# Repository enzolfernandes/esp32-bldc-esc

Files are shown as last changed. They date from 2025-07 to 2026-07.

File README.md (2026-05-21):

# Electronic Speed Controller (ESC) for BLDC Motors

## 📌 Project Overview
This repository contains the full Research and Development (R&D) cycle of a high-performance **Electronic Speed Controller (ESC)** designed for Three-Phase Brushless DC (BLDC) motors. Developed as a Senior Undergraduate Thesis in Electrical Engineering, this project bridges mathematical modeling, power electronics circuit design, and wireless embedded systems architecture.

> ⚠️ **Project Status: Work in Progress (WIP)** > The hardware design, power simulations, and mathematical modeling stages are complete. The project is currently transitioning into the embedded firmware development phase.

---

## 🛠️ Tech Stack & Engineering Tools
* **Hardware & EDA:** Altium Designer, EasyEDA
* **Simulation & Modeling:** LTspice, MATLAB/Simulink
* **Target Architecture (Planned):** C/C++, ESP32 Microcontroller, Bluetooth Core
* **Documentation:** LaTeX

---

## 📁 Repository Structure
```text
├── Docs/               # LaTeX source files for the thesis monograph and academic documentation
├── Hardware/           # Altium Designer schematics, PCB layouts, Gerber files, and BOM
├── Simulation/         # MATLAB/Simulink plant models and LTspice power stage simulations
└── Firmware/           # (Planned) Embedded C++ source code for the ESP32 microcontroller
```
---

## 📈 Engineering Stages & Implementation

### 1. Mathematical Modeling & Plant Simulation (MATLAB/Simulink)
Before physical layout development, the BLDC motor dynamics and switching characteristics were modeled mathematically. 
* **Simulink Models:** Used to evaluate back-EMF behavior, rotor position estimation, and control loop stability.
* **Control Strategy:** Theoretical foundations for vector control and electronic commutation routines were validated to ensure optimal torque and speed efficiency.

### 2. Power Stage & Signal Integrity Simulation (LTspice)
To prevent hardware failures during high-power switching events, critical sections of the circuit were simulated using LTspice.
* Transient analysis of power MOSFET switching characteristics.
* Validation of gate driver circuit performance and bootstrap capacitor sizing.
* Thermal and overcurrent protection threshold evaluation to ensure circuit robustness under power loading.

### 3. Hardware & PCB Design (Altium Designer)
The physical hardware was developed with a focus on power density, thermal dissipation, and signal integrity.
* **Schematic Capture:** Rigorous component specification targeting high efficiency and low noise figures.
* **PCB Layout:** Advanced routing using Altium Designer, featuring optimized power paths to minimize parasitic inductance and separation between high-current power stages and low-voltage digital control signals.
* **Fabrication:** Initial prototyping layouts generated via CNC routing for rapid laboratory bench testing.

---

## 🚀 Development Roadmap (Next Steps)

The next phase focuses on the execution of embedded firmware development and wireless hardware validation:

- [ ] **Firmware Architecture Setup:** Structuring the core C++ application using ESP-IDF/PlatformIO.
- [ ] **Commutation Lobbies:** Implementing hardware interrupts for precise phase switching based on sensor/sensorless feedback.
- [ ] **IoT & Wireless Connectivity:** Developing a **Bluetooth** communication layer for wireless remote control and real-time telemetry monitoring (speed, current, and temperature indexes).
- [ ] **Laboratory Bench Testing:** System debugging using oscilloscopes, logic analyzers, and signal generators to validate torque response and telemetry accuracy under real load conditions.

---

## 📬 Contact & Contributions
If you have questions regarding the hardware architecture, LTspice simulation models, or embedded IoT design, feel free to reach out.

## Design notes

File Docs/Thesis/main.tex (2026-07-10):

%=====================================================
% PREÂMBULO - CONFIGURAÇÕES GERAIS DO DOCUMENTO
%======================================================
\documentclass[12pt, a4paper, openright, oneside, chapter=TITLE, brazilian]{abntex2}

% --- PACOTES DE CODIFICAÇÃO ---
\usepackage[T1]{fontenc}
\usepackage[utf8]{inputenc}
\usepackage{mathptmx}

% --- PACOTES DE LAYOUT E FORMATAÇÃO (ABNT/UNESP) ---
\usepackage[left=3cm, top=3cm, right=2cm, bottom=2cm, headsep=1.5cm]{geometry}
\usepackage{indentfirst} % Indenta o primeiro parágrafo de cada seção
% Usando o comando nativo da classe memoir (base do abntex2) para espaçamento 1,5 [1]
\OnehalfSpacing

% --- HIERARQUIA TIPOGRÁFICA ABNT/UNESP ---
\renewcommand{\ABNTEXchapterfont}{\normalfont\bfseries}
\renewcommand{\ABNTEXchapterfontsize}{\normalsize}
\renewcommand{\ABNTEXsectionfont}{\normalfont\bfseries}
\renewcommand{\ABNTEXsectionfontsize}{\normalsize}
\renewcommand{\ABNTEXsubsectionfont}{\normalfont}
\renewcommand{\ABNTEXsubsectionfontsize}{\normalsize}
\renewcommand{\ABNTEXsubsubsectionfont}{\normalfont\bfseries\itshape}
\renewcommand{\ABNTEXsubsubsectionfontsize}{\normalsize}
\renewcommand{\ABNTEXsubsubsubsectionfont}{\normalfont\itshape}
\renewcommand{\ABNTEXsubsubsubsectionfontsize}{\normalsize}
% --- PACOTES DE BIBLIOGRAFIA (ABNT) ---
\usepackage{csquotes}
% Opções simplificadas para máxima compatibilidade.
\usepackage[backend=biber, style=abnt]{biblatex}
\addbibresource{bibliografia.bib} % Seu arquivo.bib

% --- PACOTES MATEMÁTICOS ---
\usepackage{amsmath}
\usepackage{amssymb}
\usepackage{mathtools}

% --- PACOTES PARA TABELAS E FIGURAS ---
\usepackage{graphicx}
\graphicspath{{../../}{imagens/}}

\usepackage{booktabs}
\usepackage{multirow}
\usepackage{array}
\usepackage[table]{xcolor}
\usepackage{caption}
\usepackage{subcaption}
\usepackage{float}
% --- Configurações automáticas de posicionamento ---
\renewcommand{\topfraction}{0.9}    % Permite que figuras ocupem até 90% do topo da página
\renewcommand{\bottomfraction}{0.8} % Permite que ocupem 80% da base
\renewcommand{\textfraction}{0.05}  % Permite que o texto ocupe apenas 5% da página se necessário
\renewcommand{\floatpagefraction}{0.85} % Só cria uma página só de figuras se elas ocuparem 85% dela
\usepackage[section]{placeins} % Muro invisível automático no final de cada seção
\usepackage{tikz}
\usetikzlibrary{shapes.geometric, arrows.meta, positioning, automata, backgrounds, calc}
\usepackage[american, siunitx]{circuitikz}
\captionsetup{
    format=plain,
    justification=justified,
    singlelinecheck=false,
    font=normalsize,
    labelfont=bf,
    labelsep=period
}
\newcommand{\legendafonte}[1]{{\SingleSpacing\captionsetup{font=footnotesize}\caption*{Fonte: #1}}}

% --- PACOTES ADICIONAIS ---
\usepackage{ragged2e}
\usepackage{soul}

% --- QUEBRA DE LINHA E TIPOGRAFIA ---
\usepackage{microtype}
\usepackage{xurl}
\setlength{\emergencystretch}{3em}
\tolerance=2000
\pretolerance=1000
\makeatletter
\let\breakable@origtexttt\texttt
\DeclareRobustCommand{\breakabletexttt}[1]{%
  \ifmmode
    \breakable@origtexttt{#1}%
  \else
    \begingroup
    \ttfamily
    \let\breakable@us\_
    \def\_{\breakable@us\allowbreak}%
    #1%
    \endgroup
  \fi
}
\let\texttt\breakabletexttt
\newcommand{\code}[1]{{\UrlFont\nolinkurl{#1}}}
\makeatother

% --- CONFIGURAÇÃO DE HIPERLINKS ---
\hypersetup{
    colorlinks=true,
    linkcolor=black,
    citecolor=black,
    urlcolor=black,
    pdftitle={Desenvolvimento e Análise de um Controlador Eletrônico de Velocidade para Motores de Corrente Contínua Sem Escovas},
    pdfauthor={Enzo Luiz Fernandes},
    bookmarksopen=true
}

%=====================================================
% METADADOS DO TRABALHO (PARA CAPA E FOLHA DE ROSTO AUTOMÁTICAS)
%=====================================================

\titulo{Desenvolvimento e Análise de um Controlador Eletrônico de Velocidade para Motores de Corrente Contínua Sem Escovas}
\autor{Enzo Luiz Fernandes}
\instituicao{
  Universidade Estadual Paulista -- UNESP
  \par
  Faculdade de Engenharia -- Câmpus de Ilha Solteira
  \par
  Departamento de Engenharia Elétrica
}
\local{Ilha Solteira}
\data{2026}
\orientador{Prof. Dr. Guilherme de Azevedo e Melo}
\tipotrabalho{Trabalho de Conclusão de Curso}
\preambulo{Trabalho de Conclusão de Curso apresentado à Universidade Estadual Paulista (UNESP), Faculdade de Engenharia, Câmpus de Ilha Solteira, para obtenção do título de Bacharel em Engenharia Elétrica.}

\makeatletter
\renewcommand{\folhaderostocontent}{
  \begin{center}
    {\normalfont\bfseries\imprimirautor}

    \vspace*{\fill}\vspace*{\fill}

    {\normalfont\bfseries\imprimirtitulo}

    \vspace*{\fill}

    \hspace{.45\textwidth}
    \begin{minipage}{.5\textwidth}
      {\SingleSpacing\imprimirpreambulo}
      \par
      \vspace*{1cm}
      Orientador: \imprimirorientador
    \end{minipage}

    \vspace*{\fill}\vspace*{\fill}

    \imprimirlocal
    \par
    \imprimirdata
    \vspace*{1cm}
  \end{center}
}
\makeatother

\begin{document}
\hypersetup{pageanchor=false}

% --- ELEMENTOS PRÉ-TEXTUAIS --
\begin{capa}
    \centering
    {\normalfont\bfseries\MakeUppercase{Universidade Estadual Paulista -- UNESP}\par}
    {Faculdade de Engenharia -- Câmpus de Ilha Solteira\par}
    {Departamento de Engenharia Elétrica\par}
    \vspace*{3cm}
    {\normalfont\bfseries\MakeUppercase{\imprimirautor}}
    \vfill
    \begin{center}
    {\normalfont\bfseries\MakeUppercase{\imprimirtitulo}}
    \end{center}
    \vfill
    {\imprimirlocal}
    \par
    {\imprimirdata}
    \vspace*{1cm}
\end{capa}

\imprimirfolhaderosto*

\begin{fichacatalografica}
    \vspace*{7.2cm}
    {\SingleSpacing\small
    \begin{center}
    \begin{minipage}{0.9\textwidth}
        \fbox{%
        \begin{minipage}{0.95\textwidth}
            \vspace{0.3cm}
            \begin{tabular}{@{}p{1.6cm}p{0.76\textwidth}@{}}
                F363d &
                Fernandes, Enzo Luiz\\
                &
                \hspace*{1.5em}Desenvolvimento e análise de um controlador eletrônico de velocidade para motores de corrente contínua sem escovas / Enzo Luiz Fernandes. -- Ilha Solteira, 2026\\
                &
                \hspace*{1.5em}128 p. : il., tabs., fotos\\[0.8cm]
                &
                \hspace*{1.5em}Trabalho de conclusão de curso (Bacharelado - Engenharia Elétrica) -- Universidade Estadual Paulista (UNESP), Faculdade de Engenharia, Ilha Solteira\\
                &
                \hspace*{1.5em}Orientador: Guilherme de Azevedo e Melo\\[0.8cm]
                &
                \hspace*{1.5em}1. Engenharia elétrica. 2. Motores elétricos. 3. Eletrônica de potência. 4. Sistemas embarcados. 5. Controle automático. I. Título.
            \end{tabular}
            \vspace{0.3cm}
        \end{minipage}}

        \vspace{0.2cm}
        \noindent Sistema de geração automática de fichas catalográficas da Unesp. Dados fornecidos pelo autor(a).
    \end{minipage}
    \end{center}}
\end{fichacatalografica}

% Folha de Aprovação
\begin{folhadeaprovacao} 
\begin{center}
{\normalfont\bfseries\MakeUppercase{\imprimirautor}}
\par\vspace{1cm}
{\normalfont\bfseries\MakeUppercase{\imprimirtitulo}}
\end{center}
\vspace{2cm}
\noindent\imprimirpreambulo
\par
\vspace{1cm}
\noindent Data de aprovação: 6 de julho de 2026.
\par
\vspace{1cm}
\noindent\textbf{BANCA EXAMINADORA}
\par\vspace{\onelineskip}

%Assinaturas 
\assinatura{\imprimirorientador \\ Orientador} 
\assinatura{Dr. Rodrigo Alessandro Nunes de Oliveira \\ Membro da Banca} 
\assinatura{Dr. Pablo Mauricio Portilla Hernandez \\ Membro da Banca} 

\end{folhadeaprovacao}

% RESUMO E ABSTRACT
\begin{resumo}
    Este trabalho apresenta o desenvolvimento e a análise de um protótipo de controlador eletrônico de velocidade (ESC) para motores de corrente contínua sem escovas (BLDC), utilizando o microcontrolador ESP32. A fundamentação teórica aborda a conversão eletromecânica, as constantes $K_T$, $K_V$ e $K_e$, a comutação trapezoidal de seis passos, a modulação por largura de pulso (PWM), a partida \textit{sensorless}, o controle proporcional-integral (PI) e os principais aspectos de eletrônica de potência e software embarcado aplicáveis ao acionamento. A metodologia seguiu uma abordagem de engenharia de sistemas, envolvendo o dimensionamento de uma ponte inversora trifásica, do barramento DC, dos circuitos de acionamento por \textit{gate driver}, das proteções de sobrecorrente e subtensão, do sensoriamento de corrente, da reconstrução de neutro virtual e do condicionamento da força contraeletromotriz para futura detecção de cruzamento por zero (ZCD). Também foram desenvolvidos a PCB protótipo e um \textit{firmware} modular em PlatformIO/FreeRTOS, com camada de abstração de hardware, máquina de estados, comutação seis passos via MCPWM, PWM a $20\,\text{kHz}$, malha de controle a $1\,\text{kHz}$ e interfaces de comando e telemetria. Os resultados incluem validações em LTSpice, análise dos esquemáticos e da PCB, testes estáticos de bancada e avaliação da arquitetura de \textit{firmware}. As simulações confirmaram os caminhos de corrente, o estado de alta impedância da fase não energizada e a necessidade do banco de capacitores do \textit{DC link}. Os ensaios estáticos validaram a manipulação do MCPWM, o tempo morto implementado por \textit{hardware} e as rotinas de proteção. Entretanto, a validação dinâmica integral com motor em rotação foi interrompida após o ensaio a vazio indicar consumo transiente excessivo e disparo da proteção da fonte, compatíveis com falha estrutural no estágio físico de potência. Assim, o objetivo geral foi parcialmente atingido: a base teórica, eletrônica, computacional e de \textit{firmware} foi consolidada e documentada, enquanto a operação completa do ESC permanece dependente de uma nova iteração do \textit{hardware} de potência.
    \par\vspace{\onelineskip}
    \noindent\textbf{Palavras-chave:} Motor BLDC; Controlador Eletrônico de Velocidade; ESP32; Comutação de Seis Passos; Controle Embarcado.
\end{resumo}

\begin{resumo}[Abstract]
\begin{otherlanguage*}{english}
This work presents the development and analysis of an electronic speed controller (ESC) prototype for brushless direct current (BLDC) motors using the ESP32 microcontroller. The theoretical foundation covers electromechanical energy conversion, the $K_T$, $K_V$, and $K_e$ constants, trapezoidal six-step commutation, pulse-width modulation (PWM), sensorless startup, proportional-integral (PI) control, and the main power electronics and embedded software aspects involved in the drive. The methodology followed a systems engineering approach, including the design of a three-phase inverter, the DC bus, gate-driver circuits, overcurrent and undervoltage protections, current sensing, virtual-neutral reconstruction, and back-electromotive-force signal conditioning for future zero-crossing detection (ZCD). A prototype PCB and a modular PlatformIO/FreeRTOS firmware were also developed, with a hardware abstraction layer, finite-state machine, MCPWM-based six-step commutation, $20\,\text{kHz}$ PWM, a $1\,\text{kHz}$ control loop, and command and telemetry interfaces. The results include LTSpice validations, schematic and PCB analysis, static bench tests, and firmware architecture evaluation. The simulations confirmed the current paths, the high-impedance state of the non-energized phase, and the need for the DC-link capacitor bank. The static tests validated MCPWM handling, hardware dead-time insertion, and protection routines. However, full dynamic validation with the motor rotating was interrupted after the no-load test indicated excessive transient current consumption and power-supply protection triggering, consistent with a structural fault in the physical power stage. Therefore, the main objective was partially achieved: the theoretical, electronic, computational, and firmware foundation was consolidated and documented, while complete ESC operation remains dependent on a new iteration of the power hardware.
    \par\vspace{\onelineskip}
    \noindent\textbf{Keywords:} BLDC Motor; Electronic Speed Controller; ESP32; Six-Step Commutation; Embedded Control.
\end{otherlanguage*}
\end{resumo}

% LISTAS E SUMÁRIO

\newpage
\pdfbookmark{\listfigurename}{lof}
\listoffigures*
\cleardoublepage

\pdfbookmark{\listtablename}{lot}
\listoftables*
\cleardoublepage

\begin{siglas}
    \item[ADC] Conversor analógico-digital
    \item[BLDC] Motor de corrente contínua sem escovas
    \item[CAN] \textit{Controller Area Network}
    \item[ESC] Controlador eletrônico de velocidade
    \item[FCEM] Força contraeletromotriz
    \item[FOC] Controle orientado de campo
    \item[FSM] Máquina de estados finitos
    \item[GPIO] Entrada/saída de propósito geral
    \item[HAL] Camada de abstração de hardware
    \item[MCPWM] Módulo de PWM para controle de motores
    \item[OCP] Proteção contra sobrecorrente
    \item[PCB] Placa de circuito impresso
    \item[PI] Proporcional-integral
    \item[PWM] Modulação por largura de pulso
    \item[UVLO] Bloqueio por subtensão
    \item[ZCD] Detecção de cruzamento por zero
\end{siglas}
\cleardoublepage

\begin{simbolos}
    \item[$C_{bus}$] Capacitância total do barramento CC
    \item[$D$] Ciclo de trabalho do sinal PWM
    \item[$f_{sw}$] Frequência de chaveamento
    \item[$I_A$, $I_B$, $I_C$] Correntes das fases A, B e C
    \item[$K_e$] Constante de força contraeletromotriz
    \item[$K_m$] Constante de mérito do motor
    \item[$K_T$] Constante de torque
    \item[$K_V$] Constante de velocidade
    \item[$T_e$] Torque eletromagnético
    \item[$V_{DC}$] Tensão do barramento CC
    \item[$\omega$] Velocidade angular
\end{simbolos}
\cleardoublepage

\pdfbookmark{\contentsname}{toc}
\tableofcontents*
\cleardoublepage

% --- ELEMENTOS TEXTUAIS ---
\hypersetup{pageanchor=true}
\textual

\input{capitulos/2_introducao_teorica.tex}
\input{capitulos/3_metodologia.tex}
\input{capitulos/4_resultados_discussao.tex}
\input{capitulos/5_conclusao.tex}

% --- ELEMENTOS PÓS-TEXTUAIS ---
\postextual
\printbibliography

\end{document}

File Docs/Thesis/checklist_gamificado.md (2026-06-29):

# 💽 GIG: Teste de Bancada ESC (Upload 4.1)

> **Contrato Principal:** Coletar 31 evidências experimentais para o TCC.
> **Drop Point (Pasta de Saída):** `Docs/Thesis/ensaio_bancada/AAAA-MM-DD/` *(Crie no início do dia!)*
>

### 🦾 Loadout do Rigger

- **Atuador Core:** Motor A2212/10T 1400 kV
- **Célula de Força:** Fonte 12 V / limite 3 A
- **Interface de Controle:** PS4 pareado
- **Ghost in the Shell:** Firmware Atual (Build de Teste)
- **Cyberdeck & Ferramentas:** Osciloscópio (1 canal), multímetro, pinça de corrente (opcional), notebook (Wi-Fi `ESC-Dashboard` + serial USB).

---

## 🏙️ NÓ A: Calibração Estática (Setup e Instrumentação)

Motor Desconectado. Configurações iniciais.

### ID 14: Offset INA240

- [x] **Extração Concluída (Com Reserva)**
**Ação:** Boot completo (Wi-Fi AP + PS4). Multímetro DC em OUT de cada INA240 (vs SGND). Serial: `INA240 offset`, logs `[Post-WiFi]` e `[Post-PS4]`. IDLE 30 s com motor desconectado e MCPWM desarmado.
**Extrato (Valores):** $V_{off,A}$ = 1670 mV | $V_{off,B}$ = 1480 mV | $V_{off,C}$ = 1510 mV. `[Post-WiFi]` adc_zero = 1660, bench_corr = +10 | `[Post-PS4]` adc_zero = 1640, bench_corr = +30. IDLE $I_A$: 1ª linha +0,01 A, típico +0,3 a 0,9 A, regime $\pm 0{,}1$ A, pico +1,07 A. $I_B/I_C \lesssim \pm 0{,}5$ A.
**Veredito:** Offset aprovado; zero em IDLE aprovado com reserva (~90% dentro de $\pm 0{,}5$ A em A; picos ~1 A). Deriva pós-RF no GPIO 34 (ver Setup 1a na tese).
**Datashard (Arquivo):** `14_ina240_offset.txt`

### ID 15: Ganho INA240

- [ ] **Pulado — limitação de bancada**
**Ação:** Previsto: validar $G = 20\,\text{V/V}$ na fase B ($I_{inj} \approx 1{,}0\,\text{A}$, $\Delta V_{out} \approx 20\,\text{mV}$, critério $|\varepsilon_G| \lesssim 5\,\%$).
**Veredito:** Cancelado. Sem resistor limitador $\geq 1\,\text{W}$ nem protoboard para injeção segura no shunt B (fonte única; estoque limitado a $1/4\,\text{W}$).
**Substituto:** ID 10 (dashboard $\times$ multímetro); OCP ID 02/18 (opcional).
**Datashard (Arquivo):** `15_ina240_ganho.txt` (registro do cancelamento)

### ID 16: Dead-time

- [ ] **Pendente**
**Ação:** PWM 50%, 20 kHz braço A. Tirar 2 fotos com o mesmo trigger (gate AH e gate AL) ou anotar o configurado.
**Extrato (Valores):** $t_{dead,AH \rightarrow AL}$ = ___ ns | $t_{dead,AL \rightarrow AH}$ = ___ ns
**Datashard (Arquivo):** `16_deadtime_AH.png`, `16_deadtime_AL.png`

### ID 17: $V_{GS}$ Bootstrap

- [ ] **Pendente**
**Ação:** Scope no gate HS e LS (50% duty). Verificar platô ~10–15 V (HS) e ~12 V (LS).
**Extrato (Valores):** $V_{GS,HS}$ = ___ V | $V_{GS,LS}$ = ___ V | Droop? [Sim / Não]
**Datashard (Arquivo):** `17_vgs_HS.png`, `17_vgs_LS.png`

### ID 02: Oscilograma OCP

- [ ] **Pendente**
**Ação:** DAC OCP ativo. Forçar OCP aterrando entrada (−) do LM339. 3 capturas (trigger em OC Trip descida): (1) INA240 ch A, (2) GPIO 26, (3) Gate AH.
**Extrato (Valores):** $t_{resposta} \approx$ ___ ns
**Datashard (Arquivo):** `02_ocp_ina240.png`, `02_ocp_octrip.png`, `02_ocp_gate.png`

### ID 18: Latência OCP

- [ ] **Pendente**
**Ação:** A partir das capturas do ID 02, medir tempos de propagação.
**Extrato (Valores):** $t_{OCP,total}$ = ___ ns | $t_{LM339}$ = ___ ns | $t_{IR2110,SD}$ = ___ ns
**Datashard (Arquivo):** `18_ocp_latencia.txt`

### ID 19: Ripple Vbus (AC)

- [ ] **Pendente**
**Ação:** PWM vazio 20 kHz. Scope no barramento, AC Coupling, 20 mV/div.
**Extrato (Valores):** $V_{pp,ripple}$ = ___ mV
**Datashard (Arquivo):** `19_ripple_vbus.png`

### ID 20: Ripple Teórico e ESR

- [ ] **Pendente**
**Ação:** Calcular ESR baseada no ID 19 e na fórmula $\Delta V_C$.
**Extrato (Valores):** $\Delta V_{C,teo}$ = ___ mV | $ESR_{ef}$ = ___ m$\Omega$
**Datashard (Arquivo):** `20_ripple_esr.txt`

### ID 30: Memória PlatformIO

- [ ] **Pendente**
**Ação:** Rodar `pio run` e copiar o bloco RAM/Flash.
**Extrato (Valores):** `.text` = ___ B | `.rodata` = ___ B | `.data` = ___ B | `.bss` = ___ B | RAM = ___ %
**Datashard (Arquivo):** `30_pio_memory.txt`

### ID 29: Heap Livre (Parte 1 — IDLE)

- [ ] **Pendente**
**Ação:** Ler heap via JSON com motor parado (BT+AP).
**Extrato (Valores):** $H_{livre,IDLE}$ = ___ bytes
**Datashard (Arquivo):** Anotar para salvar junto com a parte 2 em `29_heap.txt`

---

## 🌪️ NÓ B: Rampa + Wi-Fi

Motor conectado. Testes de aceleração e estabilidade.

### ID 21: Corrente de Alinhamento

- [ ] **Pendente**
**Ação:** Pinça DC na Fase A; pressionar R2; ler média durante ALIGN.
**Extrato (Valores):** $I_{align}$ = ___ A | Desvio teórico = ___ %
**Datashard (Arquivo):** `21_i_align.txt`

### ID 01: Partida FSM (Oscilograma)

- [ ] **Pendente**
**Ação:** Pinça na Fase A ou tensão Fase–GND. Gravar 30–60 s com R2. Marcar ALIGN, RUN_OPEN e RUN_SPEED.
**Extrato (Valores):** $t_{rampa,med}$ = ___ s
**Datashard (Arquivo):** `01_partida_faseA_scope.png`, `04_rampa_rpm_im.csv`

### ID 04: Gráfico Rampa RPM + Corrente

- [ ] **Pendente**
**Ação:** Exportar CSV da Dash durante o ensaio anterior (R2 completo).
**Extrato (Valores):** Regiões demarcadas com sucesso.
**Datashard (Arquivo):** `04_rampa_rpm_im.png`

### ID 05: Duração Rampa 5 Hz → 300 Hz

- [ ] **Pendente**
**Ação:** Usar o CSV do ID 04 para subtrair $t_2$ (300 Hz) e $t_1$ (5 Hz).
**Extrato (Valores):** $T_{rampa,med}$ = ___ s | $T_{rampa,teo}$ = ___ s | Desvio = ___ %
**Datashard (Arquivo):** `05_rampa_tempo.txt`

### ID 22: Correntes Trifásicas (Partida)

- [ ] **Pendente**
**Ação:** Extrair dados do CSV. Verificar simetria.
**Extrato (Valores):** ALIGN = ___ ms | $f_{el}$ transição = ___ Hz | Simetria: [Sim / Não]
**Datashard (Arquivo):** `22_partida_correntes.png`

### ID 09: Screenshot Dashboard

- [ ] **Pendente**
**Ação:** Motor RUNNING. Navegador em 192.168.4.1. Print Screen.
**Datashard (Arquivo):** `09_dashboard_screenshot.png`

### ID 10: Validação Corrente Dash vs Multímetro

- [ ] **Pendente**
**Ação:** Multímetro em série. Ler $I_{DC}$ no multímetro, `im` e `rpm`.
**Extrato (1500 RPM):** Multímetro = ___ A | Dash = ___ A | $\varepsilon_I$ = ___ %
**Extrato (2000 RPM):** Multímetro = ___ A | Dash = ___ A | $\varepsilon_I$ = ___ %
**Datashard (Arquivo):** `10_validacao_corrente.txt`

### ID 07: Coerência RPM Dashboard ↔ Serial

- [ ] **Pendente**
**Ação:** Comparar `rpm` no JSON vs UART simultaneamente.
**Extrato (Valores):** $\varepsilon$ (1500 RPM) = ___ % | $\varepsilon$ (2000 RPM) = ___ %
**Datashard (Arquivo):** `07_coerencia_rpm.txt`

### ID 11 & 12: Estabilidade Contínua Wi-Fi

- [ ] **Pendente**
**Ação:** Motor RUNNING $\geq$ 6 min. Exportar CSV da dash. Anotar métricas.
**Extrato (Valores):** $T_{ensaio}$ = ___ min | $N$ amostras = ___ | Quedas HTTP = ___ | Heap/Lat estáveis? [S / N]
**Datashard (Arquivo):** `11_csv_estabilidade.png`, `11_ensaio_estabilidade.csv`, `12_estabilidade_notas.txt`

---

## ⚡ NÓ C: Dinâmica

Testes de resposta, limites e stress mecânico.

### ID 23: Determinismo PWM

- [ ] **Pendente**
**Ação:** Motor em regime. Scope em AH, persistência/histograma $\geq$ 1 min. Apertar botões aleatórios no PS4.
**Extrato (Valores):** $T_{min}$ = ___ $\mu$s | $T_{max}$ = ___ $\mu$s | $\sigma_T$ = ___ ns
**Datashard (Arquivo):** `23_pwm_histograma.png`, `23_pwm_periodo.txt`

### ID 24: Degrau PI Corrente

- [ ] **Pendente**
**Ação:** Modo Corrente (`SPEED_MODE = 0`). R2 degrau rápido sobe/desce. Log serial.
**Extrato (Valores):** $K_p$ = ___ | $K_i$ = ___ | $t_s$ = ___ s | $M_p$ = ___ % | $e_{ss}$ = ___ A
**Datashard (Arquivo):** `24_degrau_corrente.png`, `24_degrau_corrente.csv`

### ID 06: Degrau PI Velocidade

- [ ] **Pendente**
**Ação:** Modo Speed (`SPEED_MODE = 1`). Degrau no R2. Medir tempo de acomodação.
**Extrato (Valores):** $K_p^\omega$ = ___ | $K_i^\omega$ = ___ | $t_s$ = ___ s | $M_p$ = ___ %
**Datashard (Arquivo):** `06_degrau_rpm.png`, `notas_pi.txt`

### ID 25: Frequência Mínima (Malha Aberta)

- [ ] **Pendente**
**Ação:** Reduzir R2 lentamente até vibrar/travar.
**Extrato (Valores):** $f_{el,min}$ = ___ Hz ($\approx$ ___ RPM) | Sintoma: ________________
**Datashard (Arquivo):** `25_fel_min.txt`

### ID 26: Stall Mecânico (Boss Fight!)

- [ ] **Pendente**
**Ação:** $I_{ref} \approx 1{,}5$ A. Travar eixo com segurança. Log serial (duty vai a 95%, FAULT). Dar re-arm.
**Extrato (Valores):** $t_{stall,total}$ = ___ ms | $t_{PI,sat}$ = ___ ms | $t_{det}$ = ___ ms | Re-arm limpo? [S / N]
**Datashard (Arquivo):** `26_stall_evento.png`, `26_stall_evento.csv`

---

## 📡 NÓ D: UVLO, BEMF e Métricas de Software

Ensaios de proteção, sinal e processamento.

### ID 03: UVLO Bateria 4S

- [ ] **Pendente**
**Ação:** Baixar tensão da fonte até dar FAULT. Subir até recuperar (debounce). Log serial `v` e `fault`.
**Extrato (Valores):** $V_{trip}$ = ___ V | $V_{rec}$ = ___ V | $t_{debounce} \approx$ ___ ms
**Datashard (Arquivo):** `03_uvlo_vbus.csv`, `03_uvlo_vbus.png`

### ID 08: BEMF Fase Flutuante

- [ ] **Pendente**
**Ação:** Motor no teto em malha aberta (~300 Hz). Scope 1 ch na 3ª fase vs SGND. Escala 5–20 ms/div.
**Extrato (Valores):** Capturar cruzamento por zero e forma trapezoidal.
**Datashard (Arquivo):** `08_bemf_fase_flutuante.png`

### ID 27: Latência Cenário A

- [ ] **Pendente**
**Ação:** BT + Serial (sem Wi-Fi cliente). Motor RUNNING por 30 s. Log `lat`.
**Extrato (Valores):** $t_{tick,min}$ = ___ $\mu$s | $t_{tick,max}$ = ___ $\mu$s | $\bar{t}_{tick}$ = ___ $\mu$s | $\rho_{CPU}$ = ___ %
**Datashard (Arquivo):** `27_ttick_cenario_A.csv`

### ID 28: Latência Cenário B

- [ ] **Pendente**
**Ação:** BT + Wi-Fi AP + Dashboard polling 1 Hz. Motor RUNNING 30 s. Log `lat` e `lmax`.
**Extrato (Valores):** $t_{tick,min,max,\bar{t}}$ = ___ / ___ / ___ $\mu$s | `lmax` = ___ $\mu$s
**Datashard (Arquivo):** `28_ttick_cenario_B.csv`

### ID 29: Heap Livre (Parte 2 — RUNNING)

- [ ] **Pendente**
**Ação:** Ler heap via JSON com motor rodando e dash atualizando.
**Extrato (Valores):** $H_{livre,RUNNING}$ = ___ bytes | $\Delta H$ = ___ | $\eta_{heap}$ = ___ %
**Datashard (Arquivo):** `29_heap.txt`

### ID 31: Síntese Impacto Wi-Fi

- [ ] **Pendente**
**Ação:** Compilar IDs 12, 27, 28 e 29. Calcular diferença máxima.
**Extrato (Valores):** $\Delta t_{tick,max}$ = ___ $\mu$s | $\bar{t}_{tick,B}$ = ___ $\mu$s | Quedas = ___
**Datashard (Arquivo):** `31_sintese_wifi.txt`

---

## 🏆 NÓ E: Side Quest (Opcional)

### ID 13: Boot Antes/Depois

- [ ] **Pendente**
**Ação:** Medir pico de corrente do firmware antigo vs repouso corrigido *(se tiver o binário antigo)*.
**Extrato (Valores):** $I_{pico,antigo}$ = ___ A ou [N/A]
**Datashard (Arquivo):** `13_boot_corrente.png`

---

💡 **Dica Notion:** Selecione os títulos `## NÓ A` … `## NÓ E` e converta em **Toggle Heading 2** para expandir só a fase ativa durante o ensaio.

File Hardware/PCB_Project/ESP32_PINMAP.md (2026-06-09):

# Mapa de pinos ESP32 ↔ ESC (DevKit V1 / DevKitC v4)

Referência para roteamento em `Control.SchDoc` (símbolo **U3** `DEVKIT_V1_ESP32-WROOM-32`) e PCB.

Fonte firmware: [`Firmware/include/board_config.h`](../../Firmware/include/board_config.h)  
Pinout físico: [`Docs/Thesis/imagens/esp32_devkitC_v4_pinlayout.png`](../../Docs/Thesis/imagens/esp32_devkitC_v4_pinlayout.png)

**Coexistência JTAG + ZCD:** JTAG usa GPIO **12–15** (livres de nets ESC). ZCD usa GPIO **16, 17, 5** (U3 **RX2, TX2, D5**).

> **Nota:** “Pino U3” = designador de pino no símbolo Altium (≠ número GPIO). Ex.: U3 pino **17** = **VP = GPIO36**, não GPIO17.

---

## Tabela mestra U3 ↔ GPIO ↔ função ESC / JTAG

| Pino U3 | Rótulo Altium | GPIO | `#define` / função | Net / destino |
|---|---|---|---|---|
| 30 | VIN | — | Alimentação | `Vcc 2 (+)` |
| 16 | EN | — | Reset | NC (botão EN DevKit) |
| 17 | VP | **36** | `PIN_ADC_IC` | `Isense C Out` → INA240 |
| 18 | VN | **39** | `PIN_ADC_VBAT` | `Vcc Supply Sense` |
| 4 | D2 | 2 | Livre | LED DevKit — **não usar ESC** |
| 5 | D4 | **4** | `PIN_SD_C` | `Shutdown C` → IR2110 SD |
| 8 | D5 | **5** | `PIN_ZCD_C` | `ZCD C` → LM339 BEMF (pull-up 10k) |
| 27 | D12 | **12** | **JTAG MTDI** | Header ESP-Prog — **sem ESC** |
| 28 | D13 | **13** | **JTAG MTCK** | Header ESP-Prog |
| 26 | D14 | **14** | **JTAG TMS** | Header ESP-Prog |
| 3 | D15 | **15** | **JTAG MTDO** | Header ESP-Prog |
| 9 | D18 | **18** | `PIN_PWM_CH` | `CH` → IR2110 |
| 10 | D19 | **19** | `PIN_PWM_CL` | `CL` → IR2110 |
| 11 | D21 | **21** | `PIN_PWM_AH` | `AH` → IR2110 |
| 1 | 3V3 | — | Alimentação | `Vmicro Ref` / 3,3 V |
| 12 | RX0 | 3 | Livre | UART0 programação — **não usar** |
| 13 | TX0 | 1 | Livre | UART0 programação — **não usar** |
| 6 | RX2 | **16** | `PIN_ZCD_A` | `ZCD A` → LM339 BEMF |
| 7 | TX2 | **17** | `PIN_ZCD_B` | `ZCD B` → LM339 BEMF |
| 14 | D22 | **22** | `PIN_PWM_AL` | `AL` → IR2110 |
| 15 | D23 | **23** | `PIN_PWM_BL` | `BL` → IR2110 |
| 23 | D25 | **25** | `PIN_VDAC_REF` | `Vdac Ref` → LM339 OCP (+) DAC1 |
| 24 | D26 | **26** | `PIN_OC_TRIP` | `OC Trip` ← LM339 wired-OR |
| 25 | D27 | **27** | `PIN_PWM_BH` | `BH` → IR2110 |
| 21 | D32 | **32** | `PIN_SD_A` | `Shutdown A` → IR2110 SD |
| 22 | D33 | **33** | `PIN_SD_B` | `Shutdown B` → IR2110 SD |
| 20 | D35 | **35** | `PIN_ADC_IB` | `Isense B Out` → INA240 |
| 19 | D34 | **34** | `PIN_ADC_IA` | `Isense A Out` → INA240 |
| 2, 29 | GND | — | Terra | `SGND` |

### Resumo por categoria

| Categoria | GPIO | Rótulos U3 |
|---|---|---|
| PWM MCPWM | 21, 22, 27, 23, 18, 19 | D21, D22, D27, D23, D18, D19 |
| Shutdown IR2110 | 32, 33, 4 | D32, D33, D4 |
| ADC1 (Wi-Fi OK) | 34, 35, 36, 39 | D34, D35, VP, VN |
| OCP LM339 | 25 (DAC), 26 (in) | D25, D26 |
| ZCD BEMF (reserva) | 16, 17, 5 | RX2, TX2, D5 |
| JTAG / ICE | 12, 13, 14, 15 | D12, D13, D14, D15 |
| Livres | 1, 2, 3 | TX0, D2, RX0 |

---

## Bloco JTAG (ESP-Prog)

| Sinal JTAG | GPIO | Rótulo U3 | Pino U3 |
|---|---|---|---|
| TDI / MTDI | 12 | D12 | 27 |
| TCK / MTCK | 13 | D13 | 28 |
| TMS / MTMS | 14 | D14 | 26 |
| TDO / MTDO | 15 | D15 | 3 |
| GND | — | GND | 2 ou 29 |

Recomendação PCB: header dedicado (ex. 2×5); trilhas curtas; **nenhuma** net ESC nestes pinos.

---

## Bloco ZCD BEMF (LM339)

| Net | GPIO | Rótulo U3 | Pino U3 |
|-----|---|---|---|
| ZCD A | 16 | RX2 | 6 |
| ZCD B | 17 | TX2 | 7 |
| ZCD C | 5 | D5 | 8 |

Regras de hardware:

- Saída LM339 **open-collector** + **pull-up 10 kΩ → 3,3 V** em cada fase.
- **GPIO5 (D5):** pino de strapping (VSPI CS) — pull-up externo obrigatório no comparador.
- Firmware: `BOARD_ENABLE_BEMF_ZCD 0` até hardware soldado; depois `1`.

---

## Não usar

GPIO **6–11** (flash SPI interna do módulo WROOM-32).

---

## Histórico de pinagem ZCD

| Versão | ZCD A/B/C | JTAG 12–15 |
|---|---|---|
| Inicial | 16 / 17 / 5 | Livre |
| Otimizado (intermediário) | 12 / 13 / 15 | Conflito |
| **Atual** | **16 / 17 / 5** | **Livre** |

---

## Ação Altium (`Control.SchDoc`)

1. Rotear **ZCD A/B/C** para **RX2, TX2, D5** (U3 pinos 6, 7, 8) — **não** D12/D13/D15.
2. Deixar **D12–D15** apenas para header **ESP-Prog** (No Connect no resto do ESC).
3. Confirmar demais nets conforme tabela mestra (BL em D23, Shutdown C em D4, etc.).
4. Re-exportar [`Docs/Thesis/imagens/esp32_schematic.png`](../../Docs/Thesis/imagens/esp32_schematic.png).

---

## Validação GPIO (sem overlap)

- **ESC ativo:** 4, 5, 16, 17, 18, 19, 21, 22, 23, 25, 26, 27, 32, 33, 34, 35, 36, 39 (18 pinos)
- **JTAG exclusivo:** 12, 13, 14, 15
- **ZCD** compartilha 16, 17, 5 com ESC reserva — mesmos pinos, nets ZCD quando BEMF existir

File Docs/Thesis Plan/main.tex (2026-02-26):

\documentclass[12pt, a4paper]{article}
\usepackage[style=abnt]{biblatex}
\addbibresource{bibliografia.bib}
\usepackage[utf8]{inputenc} %Pacote para acentuação
\usepackage{csquotes}
\usepackage[portuguese,brazilian]{babel}
\usepackage[lmargin=3cm,tmargin=3cm,rmargin=2cm,bmargin=2cm]{geometry} %Formato que lembra a ABNT
\usepackage[T1]{fontenc} %Ajusta o texto que vem de outras fontes
\usepackage{amsmath,amsthm,amsfonts,amssymb,dsfont,mathtools,blindtext} %pacotes matemáticos
\usepackage{blindtext} %Texto aleatório
\usepackage{graphicx} %imagens
\usepackage{indentfirst}
\usepackage{booktabs, multirow} % for borders and merged ranges
\usepackage{soul}% for underlines
\usepackage[table]{xcolor} % for cell colors
\usepackage{changepage,threeparttable} % for wide tables
\usepackage{caption}
\usepackage{float}
\usepackage{multirow}
\usepackage{colortbl}
\usepackage{hhline}
\usepackage{array}
\usepackage{ragged2e}

\begin{document}

%% Capa
\begin{titlepage}
	\begin{center} %centralizar o texto abaixo
		{\begin{figure}[ht]
				\centering
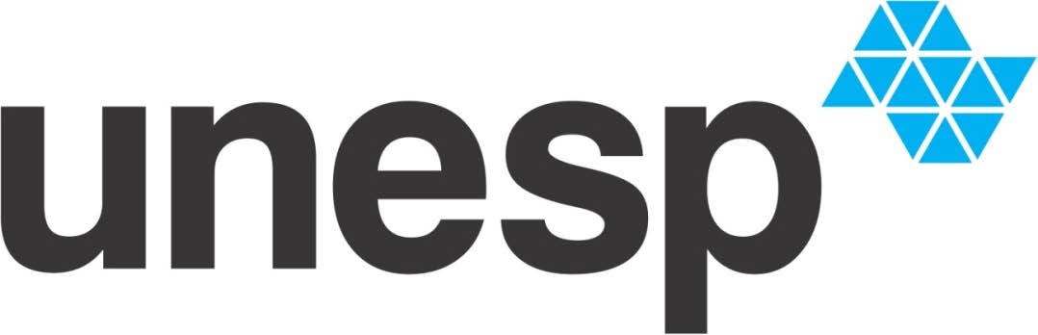
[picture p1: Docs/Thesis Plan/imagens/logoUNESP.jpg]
				
			\end{figure}}
		{\bf \large FEIS – FACULDADE DE ENGENHARIA DE ILHA SOLTEIRA}\\[0.2cm] % o comando \\ "manda" o texto ir para próxima linha
		{\bf \large DEE – DEPARTAMENTO DE ENGENHARIA ELÉTRICA}\\[4cm]

        {\bf \large ENZO LUIZ FERNANDES}\\[4cm]

		{\bf \huge Plano de Trabalho de Graduação}\\[0.2cm] % o comando \bf deixa o texto entre chaves em negrito. O comando \huge deixa o texto enorme

		{\bf \Large Desenvolvimento e Análise de um Controlador Eletrônico de Velocidade para Motores de Corrente Contínua Sem Escovas}\\

	\end{center} %término do comando centralizar

	\vspace*{\fill} % Sempre na parte inferior da página
	\begin{center}
		{\large Ilha Solteira.}\\[0.2cm]

		{\large 2026}

	\end{center}
\end{titlepage}

%% Sumário
\newpage
\tableofcontents
\thispagestyle{empty}
\pagebreak

%-----------------------------------------------
\section{Introdução Teórica}

Os motores BLDC (\textit{Brushless Direct Current Motor}) representam um avanço significativo em relação aos motores CC tradicionais porque eliminam a necessidade de escovas mecânicas para a conversão de energia, resultando em maior rendimento energético, menos desgaste e maior vida útil \cite{hanselman2003brushless}. Esses avanços tecnológicos estão sendo impulsionados pela crescente demanda por sistemas de acionamento mais eficientes, confiáveis e de baixa manutenção em diversas aplicações industriais, comerciais e de consumo. A precisão e controlabilidade dos motores BLDC os tornam ideais para aplicações que exigem alta exatidão de movimento, velocidade e controle de torque, como robótica, automação industrial, veículos elétricos e eletrônicos de consumo.

\subsection{Motores CC Sem Escova}
O princípio de funcionamento dos motores BLDC é baseado em campos magnéticos gerados por ímãs permanentes e enrolamentos de  (Figura \ref{Configuração de um motor DC convencional (A) e motor BLDC (B).}). A comutação da corrente para gerar movimento ocorre eletronicamente, por meio de um controlador dedicado normalmente chamado de ESC (Eletronic Speed Controller), que pode usar ou não sensores durante o processo, eliminando assim a necessidade de escovas mecânicas utilizadas em motores DC tradicionais. Esta abordagem resulta em uma diminuição significativa do desgaste mecânico, aumentando a vida útil do motor e reduzindo a necessidade de manutenção.

\begin{figure}[h]
	\centering
	\caption{Configuração de um motor DC convencional (A) e motor BLDC (B).}
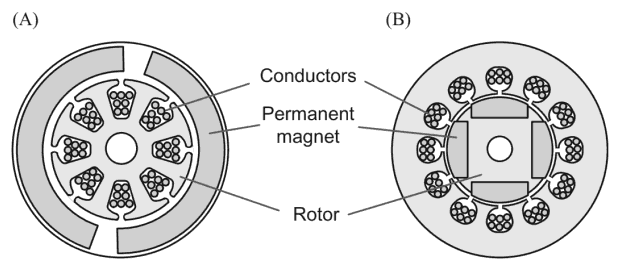
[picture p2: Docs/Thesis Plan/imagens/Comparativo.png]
	
	\caption*{Fonte:\cite{kim2017electric}.}
 \label{Configuração de um motor DC convencional (A) e motor BLDC (B).}
\end{figure}

Os motores BLDC são amplamente utilizados em uma variedade de aplicações, desde eletrônicos de consumo, como ventiladores e ferramentas elétricas, até aplicações industriais e automotivas. Sua capacidade de fornecer um controle preciso de velocidade e posição, juntamente com uma resposta rápida, faz deles a escolha ideal para sistemas que exigem rendimento energético e alta performance.

Apesar das muitas vantagens, os motores BLDC não estão isentos de algumas limitações. A complexidade eletrônica necessária para o controle preciso, o custo inicial potencialmente mais elevado comparado a motores elétricos escovados, a sensibilidade a ambientes de alta temperatura, pois podem gerar a desmagnetização dos imãs permanentes, a exigência de eletrônica de controle especializada, o potencial de ruído eletromagnético (EMI) e a complexidade de manutenção do sistema como um todo são fatores a serem considerados ao escolher essa tecnologia. Cada aplicação específica deve ponderar essas considerações em relação aos benefícios que os BLDC oferecem, como rendimento, durabilidade e controle superior.

\subsubsection{Princípios de Construção}

Motores BLDC são categorizados como síncronos, ou seja, o rotor gira na mesma frequência do campo magnético gerado pelo estator \cite{jahns1984torque}. Também não apresentam o fenômeno de escorregamento que é característico dos motores de indução. Os motores BLDC estão disponíveis em configurações de uma fase, duas fases e três fases, sendo  essa a mais amplamente utilizada, por serem equilibrados em relação a oscilação de torque e custo de construção \cite{hendershot1994design}.

\subsection{Controlador Eletrônico de Velocidade (ESC)}
Os controladores eletrônicos de velocidade, são dispositivos eletrônicos que controlam a velocidade e o torque de motores BLDC. São classificados pela sua corrente e tensão máxima de saída. São constituídos dos seguintes componentes básicos:

\begin{itemize}
\item Circuito de entrada: O circuito de entrada converte a tensão fornecida pela bateria em tensão que pode ser usada pelo circuito de controle utilizando PWM para gerar uma tensão média desejada que será fornecida ao motor. Também pode inverter a sequência de comutação das fases fazendo com que o sentido de rotação também seja invertido.
\item Circuito de controle: O circuito de controle é responsável por calcular a corrente que deve ser fornecida às bobinas do motor. Normalmente se utilizam de sinais com características de PWM como sinal de referência para definir a velocidade e sentido de rotação.
\item Circuito de saída: O circuito de saída fornece a corrente necessária às bobinas do motor.
\end{itemize}

Além desses componentes básicos, os ESCs para motor BLDC pode incluir os seguintes recursos, além dos já discutidos anteriormente:

\begin{itemize}
\item Filtro de ruído: O filtro de ruído é usado para reduzir o ruído elétrico que pode ser gerado pelo motor.
\item Proteção térmica: A proteção térmica é usada para proteger o motor de superaquecimento.
\item Proteção contra sobrecarga: O ESC pode desligar o motor se ele experimentar correntes superiores às nominais que representam riscos de deterioração das bobinas do motor.
\end{itemize}

\subsection{Princípios de Operação}

 O controlador do motor deve fornecer corrente e tensão adequadas às bobinas do estator do motor, a fim de controlar a velocidade e o torque do motor \cite{jahns1996pulsating}. O circuito básico que realiza esse papel é o de uma ponte inversora trifásica, onde o motor BLDC pode estar conectado em Estrela ou Delta. O controle do circuito de disparo dos transistores do inversor deve ser feito de forma que cada fase do estator seja percorrida por uma corrente com a forma de onda senoidal ou trapezoidal, voltadas respectivamente para alto rendimento e baixo custo. As formas de onda de cada uma das fases devem estar defasadas entre si, permitindo que o motor gire de forma contínua.

\subsubsection{Comutação de Seis Passos}

A comutação de seis passos demanda um sincronismo de disparo dos transistores, de modo que sempre dois deles estejam fechados, formando um circuito tal que a cada $60 ^\circ$ elétricos o par de fases percorridas pela corrente se alterne (Figura \ref{Sequência de acionamento para um BLDC trifásico}). Cada transistor permanece em condução durante $120 ^\circ$ elétricos. Vale ressaltar que os eventos de condução e bloqueio, denominados comutações dos transistores, geram variações na corrente e isso é responsável pelas oscilações no torque do motor \cite{kim2017electric}. 

\begin{figure}[p]
	\centering
	\caption{Sequência de acionamento para um BLDC trifásico.}
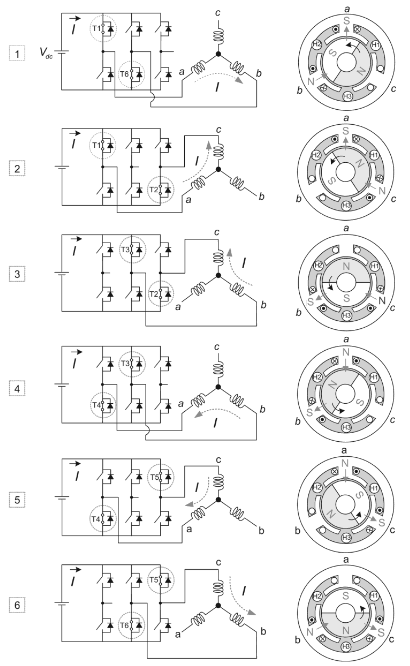
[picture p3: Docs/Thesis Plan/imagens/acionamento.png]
	
	\caption*{Fonte:\cite{kim2017electric}.}
 \label{Sequência de acionamento para um BLDC trifásico}
\end{figure}

Esse é o algoritmo de acionamento dos transistores mais amplamente utilizado para controlar motores BLDC e é também chamada de Controle Trapezoidal. Para se saber quando e quais deles acionar, existem duas opções, saber a posição que o rotor se encontra de forma a acionar o conjunto de transistores seguinte. Para esse tipo de controle se dá o nome de Controle de Malha Fechada. Também é possível acionar os indutores a partir de uma sequência fixa determinada pelo circuito, o que faz com que o rotor comece a girar em algum momento da sequência e siga girando a partir da sequência determinada. Esse tipo de controle é mais simples e de menor custo, porém não tão preciso, recebendo o nome de Controle de Malha Aberta.

 Para a realização do Controle de Malha Fechada é possível usar um sensor de efeito Hall capaz de identificar o campo magnético resultante da interação do campo eletromagnético das bobinas e do campo magnético dos imãs permanentes do rotor, indicando a seção que o campo eletromagnético resultante encontra-se, ou seja, sua posição angular. Partindo dessa referência, se pode saber quais transistores devem ser acionadas para que o rotor continue a girar. A utilização de sensor Hall também propicia a determinação da velocidade angular do motor. Esse método é mais complexo e de maior custo, porém garante uma maior confiabilidade em relação a velocidade.

Quando a aplicação necessita que o motor possua apenas uma velocidade, a fonte de alimentação de tensão fixa é suficiente, mas para casos onde é necessário varia a velocidade do motor precisa-se de uma ponte trifásica com controle PWM, um ESC por exemplo, entretanto essa técnica demanda a utilização de controladores que comparem a velocidade desejada da medida no rotor.

\newpage

\subsubsection{Modulação por Largura de Pulso}

Fontes de tensão fixa, como baterias, são as mais acessíveis do mercado. A partir delas, é possível gerar uma tensão média de alimentação variável utilizando uma técnica conhecida como PWM (Modulação por Largura de Pulso), permitindo o controle de velocidade de um BLDC. Para isso, utiliza-se um circuito simples capaz de transformar a tensão contínua em uma onda quadrada de frequência fixa e amplitude igual à tensão da fonte de alimentação. A própria ponte trifásica pode ajustar a largura dos pulsos, fazendo com que a tensão média entregue à ponte inversora seja proporcional à velocidade desejada (Figura \ref{Modulação por largura de pulso utilizando uma fonte de 100V}).

\begin{figure}[h]
	\centering
	\caption{Modulação por largura de pulso utilizando uma fonte de $100V$.}
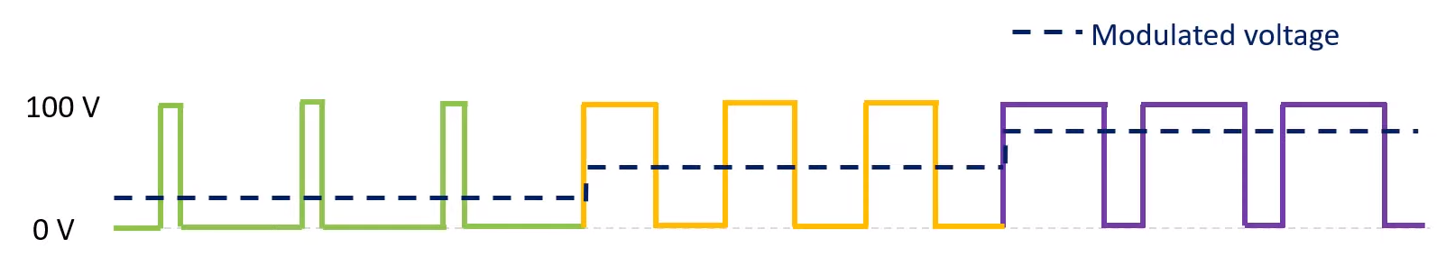
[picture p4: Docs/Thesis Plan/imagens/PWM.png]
	
	\caption*{Fonte:\cite{matlabBLDC}.}
 \label{Modulação por largura de pulso utilizando uma fonte de 100V}
\end{figure}

\subsubsection{Outros Algoritmos de Controle}

Além do Controle Trapezoidal existem outras formas de controle que envolvem algorítimos mais complexos, como o Controle de Torque Vetorial e o Controle de Campo Orientado, ambos em malha fechada.

No controle de torque vetorial, o controlador de motor calcula a corrente que deve ser fornecida às bobinas do estator usando um modelo matemático do motor. O modelo matemático do motor descreve a relação entre a corrente nas bobinas do estator, o campo magnético do rotor e o torque produzido pelo motor. O controlador vetorial de torque do motor calcula o torque desejado e, em seguida, usa o modelo matemático do motor para calcular a corrente necessária para produzir o tal torque. Este controle é um método preciso e flexível que pode ser usado em uma variedade de aplicações. Ele é adequado para aplicações onde a exatidão de velocidade e torque é crítica

No controle de campo orientado, o controlador do motor calcula a corrente que deve ser fornecida às bobinas do estator usando a orientação do campo magnético do rotor. O controlador de motor usa um sensor para medir a orientação do campo magnético do rotor, sendo que o sensor envia um sinal para o controlador, o utiliza sinal para calcular a corrente necessária para manter o campo magnético do rotor na orientação desejada. O controle de campo orientado é um método preciso e eficiente que pode ser usado em aplicações de alta velocidade.

\pagebreak

\subsection{Vantagens e Desvantagens no uso de motores BLDC}
Os motores sem escovas, ou BLDC, apresentam diversas vantagens que contribuem para seu destaque em várias aplicações. O rendimento é uma característica proeminente, uma vez que convertem mais eficientemente a energia elétrica em torque quando comparados aos motores com escovas. Isso implica em uma demanda menor de energia para gerar a mesma quantidade de torque, resultando em um melhor desempenho global. A durabilidade é significativamente aprimorada, visto que a vida útil estendida desses motores está relacionada à ausência das escovas, componentes propensos a desgaste em motores convencionais.

Os motores de indução trifásicos (MIT) são concorrentes diretos dos motores BLDC, sendo que ambos são amplamente utilizados em diversas aplicações, cada uma com suas características distintas e vantagens específicas. Os motores de indução trifásicos são conhecidos pela sua confiabilidade, simplicidade de construção e custo relativamente baixo, quando comparado aos BLDC, utilizando os princípios da indução eletromagnética para gerar o torque e velocidade necessários para a aplicação. Embora tenham menor custo de produção quando comparados com os motores BLDC e podem ser controlados utilizando os mesmos protocolos, os MITs tendem a ter uma densidade de potência e torque menor em comparação com os motores BLDC, principalmente em baixas velocidades, o que pode ser uma consideração importante em aplicações que requerem alta potência em um espaço limitado. No entanto, os MITs apresentam melhor rendimento em operações de baixo torque, o que pode ser relevante em aplicações de mobilidade, como em veículos elétricos.

Os motores BLDC são conhecidos por seu rendimento energético superior, controle preciso de velocidade e torque, além de uma vida útil mais longa devido à ausência de escovas mecânicas \cite{gieras2009permanent}. Embora os BLDCs tenham um custo inicial mais elevado em comparação com os MITs, eles oferecem uma operação mais eficiente, especialmente em condições de carga variável e velocidade ajustável.

Em resumo, os motores sem escovas oferecem um conjunto de vantagens notáveis, incluindo rendimento aprimorado, operação mais silenciosa, maior durabilidade e menor necessidade de manutenção. Contudo, esses benefícios vêm com um custo inicial mais elevado e a exigência de um controlador de velocidade, o que pode tornar sua implementação menos acessível em certos contextos. A escolha entre motores com escovas e sem escovas dependerá das prioridades específicas de uma aplicação, considerando tanto os benefícios quanto as limitações de cada tecnologia.

\pagebreak

\subsection{Aplicações}
Os motores BLDC são amplamente utilizados em diversas aplicações devido às suas características únicas, como elevado rendimento, alta densidade de potência, baixo ruído, baixa manutenção e longa vida útil. Esses motores são preferidos em aplicações que necessitam de controle preciso de torque com oscilações inferiores em comparação com outros motores.

Uma das principais aplicações dos motores BLDC é em veículos elétricos, como carros, motocicletas, bicicletas e \textit{scooters} \cite{chau2007emerging}. Com o aumento da demanda por veículos elétricos, espera-se que os motores com tecnologia derivada do BLDC desempenhem um papel vital na indústria automotiva. Esses motores são usados para acionar o sistema de propulsão do veículo, fornecendo torque e potência para as rodas. Eles são preferidos em veículos elétricos devido à seu alta rendimento, baixo ruído e baixa manutenção. Essas motores são usados em aplicações que exigem alta precisão, controle de velocidade e torque, e baixo ruído.

\section{Objetivos}
Estudar o princípio de funcionamento de um controlador de motores Brushless, tornando possível o projeto e desenvolvimento de um protótipo que possa oferecer uma operação suave e precisa em diferentes cenários de aplicação.

\section{Metodologia}
O desenvolvimento do ESC será realizado em três etapas principais. A primeira conta com uma simulação computacional do sistema para entender a transformação da energia elétrica e a coordenação dos chaveamentos, analisando o controle de rotação e velocidade do motor. Em seguida, na fase de projeto, serão definidos os requisitos mínimos, escolhidos os componentes eletrônicos e desenvolvido o circuito, incluindo controle de tensão, corrente com sinais PWM e proteções. Por último, na prototipagem, o controlador será montado em uma PCB, programado e testado em laboratório para garantir o funcionamento e identificar melhorias.

\subsection{Simulação}
Para o desenvolvimento de um ESC, primeiramente, apresenta-se a simulação do sistema via software, permitindo assim um maior entendimento de cada etapa de transformação da energia elétrica, como a metodologia adotada para coordenação dos chaveamentos, sem as limitações físicas impostas na implementação do circuito real. A simulação gera uma análise teórica funcional sobre o controle de sentido de rotação e velocidade imposta ao motor.

\pagebreak

\subsection{Projeto}
Para a elaboração do projeto físico é necessário o levantamento dos requisitos mínimos que o projeto deve atender, como a categoria de motores que deve atender e sua fonte de alimentação. Em seguida será necessária a seleção dos componentes eletrônicos (drivers, transistores, bateria, entre outros), considerando características como um controlador adequado, tensão de operação, frequência de comutação, corrente máxima suportada e possíveis proteções para o sistema.

O projeto do circuito começa pelo controle de tensão, em seguida será projetado o controle de corrente fornecida às bobinas do motor através de sinais de PWM para controle de velocidade e sentido de rotação, ou seja o drive para motor BLDC e recursos adicionais como proteções térmicas ou de sobrecarga.

\subsection{Prototipagem}
Com o fim do projeto do circuito inicia-se a implementação do controlador em uma placa de circuito impresso (PCB) por meio de um software de design eletrônico. Com a montagem dos componentes na PCB, será necessária a programação do microcontrolador implementado a lógica de chaveamento e outras funções. Também serão realizados teste de funcionamento em laboratório para garantir o funcionamento correto do circuito e levantar possíveis melhorias ou correções. Após as devidas correções serão realizados testes de desempenho afim de verificar se o projeto atende os requisitos estabelecidos de potência e tempo de resposta.

Todas as partes relevantes durante o trabalho de graduação serão documentadas através da redação do relatório acadêmico e apresentação para a defesa do trabalho de graduação.

\section{Cronograma}

O desenvolvimento deste trabalho, está previsto nas seguintes etapas e distribuído de acordo com a Tabela \ref{Cronograma proposto de atividades.}:

\begin{table}[h]
\centering
\caption{Cronograma atualizado de atividades do projeto.}
\label{Cronograma proposto de atividades.}
\resizebox{\linewidth}{!}{%
\begin{tabular}{|c|l|c|c|c|c|c|} 
\cline{3-7}
\multicolumn{1}{c}{} & \multicolumn{1}{c|}{} & \multicolumn{5}{c|}{\textbf{Mês (2026)}} \\ 
\cline{3-7}
\multicolumn{1}{l}{} &  & 02 & 03 & 04 & 05 & 06 \\ 
\hline
\multirow{7}{*}{\textbf{Atividades}} & Simulação do Circuito & {\cellcolor[rgb]{0.753,0.753,0.753}} & {\cellcolor[rgb]{0.753,0.753,0.753}} &  &  &  \\ 
\hhline{|~------|}
 & Projeto da Placa (PCB) e Compras & {\cellcolor[rgb]{0.753,0.753,0.753}} & {\cellcolor[rgb]{0.753,0.753,0.753}} &  &  &  \\ 
\hhline{|~------|}
 & Prototipagem e Soldagem &  & {\cellcolor[rgb]{0.753,0.753,0.753}} & {\cellcolor[rgb]{0.753,0.753,0.753}} &  &  \\ 
\hhline{|~------|}
 & Testes Iniciais (Sinais e PWM) &  &  & {\cellcolor[rgb]{0.753,0.753,0.753}} & {\cellcolor[rgb]{0.753,0.753,0.753}} &  \\ 
\hhline{|~------|}
 & Correções e Ajustes Físicos &  &  &  & {\cellcolor[rgb]{0.753,0.753,0.753}} &  \\ 
\hhline{|~------|}
 & Testes de Carga com o Motor &  &  &  & {\cellcolor[rgb]{0.753,0.753,0.753}} & {\cellcolor[rgb]{0.753,0.753,0.753}} \\ 
\hhline{|~------|}
 & Escrita do Texto e Defesa &  &  &  & {\cellcolor[rgb]{0.753,0.753,0.753}} & {\cellcolor[rgb]{0.753,0.753,0.753}} \\
\hline
\end{tabular}
}
\caption*{Fonte: Produção do próprio autor.}
\end{table}

%% Bibliografia
\newpage
\printbibliography[heading=bibintoc, title={Bibliografia}]
\pagebreak

%% Assinaturas
\newpage
\section*{Assinaturas}
\addcontentsline{toc}{section}{Assinaturas}

\begin{center}

\vspace{2cm}
\begin{tabular}{@{}p{7cm}@{}}
	\hrulefill       \\

	\textbf{Aluno:} \\
	Enzo Luiz Fernandes
\end{tabular}

\vspace{2cm}
\begin{tabular}{@{}p{7cm}@{}}
	\hrulefill                     \\
	\textbf{Professor Orientador:} \\
	Guilherme de Azevedo Melo
\end{tabular}

\end{center}
\pagebreak

%-----------------------------------------------
\end{document}

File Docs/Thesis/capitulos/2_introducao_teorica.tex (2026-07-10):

\chapter{Introdução}

Os motores BLDC (\textit{Brushless Direct Current Motor}) representam um avanço significativo em relação aos motores CC tradicionais porque eliminam a necessidade de escovas mecânicas para a conversão de energia, resultando em maior rendimento energético, menos desgaste e maior vida útil \cite{hanselman2003brushless}. Esses avanços tecnológicos estão sendo impulsionados pela crescente demanda por sistemas de acionamento de maior rendimento, confiáveis e de baixa manutenção em diversas aplicações industriais, comerciais e de consumo. A precisão e controlabilidade dos motores BLDC os tornam ideais para aplicações que exigem alta exatidão de movimento, velocidade e controle de torque, como robótica, automação industrial, veículos elétricos e eletrônicos de consumo.

\input{capitulos/1_objetivos.tex}

\section{Motores CC Sem Escova}
O princípio de funcionamento dos motores BLDC é baseado em campos magnéticos gerados por ímãs permanentes e enrolamentos de  (Figura \ref{fig:motor-dc-bldc-comparativo}). A comutação da corrente para gerar movimento ocorre eletronicamente, por meio de um controlador dedicado normalmente chamado de ESC (Eletronic Speed Controller), que pode usar ou não sensores durante o processo, eliminando assim a necessidade de escovas mecânicas utilizadas em motores DC tradicionais. Esta abordagem resulta em uma diminuição significativa do desgaste mecânico, aumentando a vida útil do motor e reduzindo a necessidade de manutenção. Os motores BLDC são amplamente utilizados em uma variedade de aplicações, desde eletrônicos de consumo, como ventiladores e ferramentas elétricas, até aplicações industriais e automotivas. Sua capacidade de fornecer um controle preciso de velocidade e posição, juntamente com uma resposta rápida, faz deles a escolha ideal para sistemas que exigem rendimento energético e alta performance.

\begin{figure}[H]
	\centering
	\caption{Configuração de um motor DC convencional (A) e motor BLDC (B).}
	
	\legendafonte{\cite{kim2017electric}.}
 \label{fig:motor-dc-bldc-comparativo}
\end{figure}

Apesar das muitas vantagens, eles não estão isentos de algumas limitações. A complexidade eletrônica necessária para o controle preciso, o custo inicial potencialmente mais elevado comparado a motores elétricos escovados, a sensibilidade a ambientes de alta temperatura, pois podem gerar a desmagnetização dos imãs permanentes, a exigência de eletrônica de controle especializada, o potencial de ruído eletromagnético (EMI) e a complexidade de manutenção do sistema como um todo são fatores a serem considerados ao escolher essa tecnologia. Cada aplicação específica deve ponderar essas considerações em relação aos benefícios que os BLDC oferecem, como rendimento, durabilidade e controle superior.

São categorizados como síncronos, ou seja, o rotor gira na mesma frequência do campo magnético gerado pelo estator \cite{jahns1984torque}. Também não apresentam o fenômeno de escorregamento que é característico dos motores de indução. Os motores BLDC estão disponíveis em configurações de uma fase, duas fases e três fases, sendo  essa a mais amplamente utilizada, por serem equilibrados em relação a oscilação de torque e custo de construção \cite{hendershot1994design}.

A nomenclatura "Brushless DC" pode gerar uma interpretação equivocada. Embora alimentado por uma fonte de corrente contínua (DC), o motor BLDC é, em sua essência, um motor síncrono de ímãs permanentes (PMSM) \parencite{maquinasEletricasFitzgerald}. A rotação é induzida por campos magnéticos girantes gerados nos enrolamentos do estator, que são alimentados por formas de onda de corrente alternada (AC) sintetizadas por um controlador eletrônico. Portanto, a designação "DC" refere-se à fonte de alimentação externa, e não ao princípio físico de operação interna, que requer uma lógica de controle sofisticada para operar \parencite{ti2013sensorless}.

Nesse contexto, a performance do sistema é governada por parâmetros intrínsecos que descrevem a física da conversão de energia. Duas das mais importantes dessas constantes são a \textbf{constante de torque ($K_T$)} e a \textbf{constante de velocidade ($K_V$)}. Estes parâmetros são a manifestação matemática dos princípios físicos que regem a interação entre os domínios elétrico e mecânico do motor.

\subsection{Fundamentos Físicos da Conversão Eletromecânica}

A operação de um motor elétrico é governada por dois princípios físicos interligados: a Força de Lorentz, que gera o torque, e a Lei da Indução de Faraday, que gera uma força contraeletromotriz.

\subsubsection{A Força de Lorentz e a Condição de Torque Máximo}

A produção de força mecânica em um motor origina-se na Força de Lorentz. Esta lei descreve a força ($\vec{F}$) sobre um condutor de comprimento vetorial ($\vec{L}$) percorrido por uma corrente ($I$) e imerso em um campo magnético ($\vec{B}$). A relação vetorial é:
\begin{equation}
    \vec{F} = I \cdot (\vec{L} \times \vec{B})
\end{equation}
A magnitude desta força, $F = I \cdot L \cdot B \cdot \sin(\theta)$, onde $\theta$ é o ângulo entre o condutor e o campo magnético, é maximizada quando $\sin(\theta) = 1$, o que ocorre precisamente quando $\theta = 90^{\circ}$. Esta condição de ortogonalidade é o princípio mais elementar para a máxima conversão de energia.

Em um motor rotativo, o objetivo é o torque, que pode ser entendido como a interação entre o campo magnético gerado pelo estator ($\vec{B}_{\text{estator}}$) e o campo gerado pelos ímãs permanentes do rotor ($\vec{B}_{\text{rotor}}$). O torque eletromagnético ($\vec{T}_{em}$) é o produto vetorial desses dois campos \cite{vas1998vector}:
\begin{equation}
    \vec{T}_{em} \propto \vec{B}_{\text{estator}} \times \vec{B}_{\text{rotor}}
\end{equation}
A magnitude do torque é, portanto, diretamente proporcional ao seno do ângulo elétrico ($\theta_e$) entre os dois vetores de campo. O torque máximo é alcançado quando este ângulo é mantido em 90 graus elétricos. Manter esta condição de ortogonalidade de forma contínua é o objetivo central das estratégias de controle de alto desempenho, como o Controle Orientado por Campo (FOC), pois garante não apenas o torque máximo para uma dada corrente, mas também o máximo rendimento na conversão eletromecânica.

\subsubsection{A Lei de Faraday}
Simultaneamente à produção de torque, um motor em rotação atua como um gerador. A Lei da Indução de Faraday afirma que a variação do fluxo magnético através de uma espira de fio induz uma força eletromotriz (FEM). Em um motor, o movimento dos ímãs do rotor em relação aos enrolamentos do estator induz uma tensão conhecida como \textbf{força contraeletromotriz (FCEM)}, ou \textit{back-EMF}.

De acordo com a Lei de Lenz, a polaridade desta tensão induzida ($e_a$) se opõe diretamente à tensão terminal ($V$) aplicada ao motor \parencite{infineon2011bldc}. A magnitude da FCEM é diretamente proporcional à velocidade angular ($\omega$) do motor, estabelecendo a ligação física entre o movimento mecânico (velocidade) e um fenômeno elétrico (tensão induzida).

\subsection{Modelo Matemático do Motor e a Definição das Constantes}

Os princípios de Lorentz e Faraday são sintetizados em um modelo matemático que descreve a dinâmica do motor.

\textbf{Equação Elétrica (Lei de Kirchhoff):}
\begin{equation}
    V = e_a + I_a \cdot R_a + L_a \cdot \frac{dI_a}{dt}
\end{equation}
Onde $V$ é a tensão aplicada, $e_a$ é a FCEM de Armadura, $I_a \cdot R_a$ é a queda de tensão resistiva de Armadura e $L_a \cdot \frac{dI_a}{dt}$ é a queda de tensão indutiva de Armadura \parencite{maquinasEletricasFitzgerald}. Vale ressaltar que Armadura é o termo técnico para o enrolamento em motores elétricos, onde a principal conversão de energia acontece.

\textbf{Equação Mecânica (2ª Lei de Newton para Rotação):}
\begin{equation}
    T_e = T_l + J \cdot \frac{d\omega}{dt} + B \cdot \omega
\end{equation}
Onde $T_e$ é o torque eletromagnético, $T_l$ é o torque de carga, $J \cdot \frac{d\omega}{dt}$ é o torque inercial e $B \cdot \omega$ é o torque de atrito viscoso \parencite{maquinasEletricasFitzgerald}.

Dentro deste modelo, as constantes do motor surgem como os fatores de proporcionalidade que conectam os domínios elétrico e mecânico.

\subsection{\texorpdfstring{A constante de Torque $K_T$}{A constante de Torque KT}}
\label{KT}
A constante de torque ($K_T$) define a capacidade de um motor de converter corrente elétrica em torque mecânico. É formalmente definida como a relação linear:
\begin{equation}
    T_e = K_T \cdot I_a
\end{equation}
O valor de $K_T$ não é arbitrário, mas determinado pelas características construtivas do motor \parencite{hendershot1994design}:
\begin{itemize}
    \item \textbf{Força do Campo Magnético ($B$):} Ímãs mais fortes (ex: Neodímio) resultam em um $K_T$ maior.
    \item \textbf{Configuração do Enrolamento:} É diretamente proporcional ao número de espiras ($N$) nos enrolamentos.
    \item \textbf{Geometria do Motor:} Dimensões como o comprimento e o raio do estator influenciam diretamente seu valor.
\end{itemize}
Para um dado torque de carga, um motor com $K_T$ maior demandará uma corrente menor, resultando em menores perdas por efeito Joule ($P = I^2 \cdot R$) e, portanto, maior rendimento.

\subsection{\texorpdfstring{As constantes de Velocidade $K_V$}{As constantes de Velocidade KV}}
\label{KV}

De forma análoga, a relação entre a FCEM e a velocidade é quantificada por constantes.
\begin{itemize}
    \item \textbf{Constante de FCEM ($K_e$):} É a constante física que relaciona a FCEM gerada ($e_a$) com a velocidade angular do motor ($\omega$):
    \begin{equation}
        e_a = K_e \cdot \omega
    \end{equation}
    Assim como $K_T$, $K_e$ (também denotado como $k_b$) depende do projeto físico do motor \parencite{zoltan2012understanding}.

    \item \textbf{Constante de Velocidade ($K_V$):} Muito mais comum em folhas de dados comerciais, $K_V$ é definida como a relação entre a velocidade do motor sem carga e a tensão aplicada, geralmente em unidades de \textbf{RPM/V}. A relação entre $K_V$ e $K_e$ é de simples inversão \parencite{infineon2011bldc}:
    \begin{equation}
        K_V = \frac{1}{K_e}
    \end{equation}
    A FCEM é o mecanismo que limita a velocidade máxima do motor. O motor acelera até que a FCEM ($e_a = K_e \cdot \omega$) se aproxime da tensão de alimentação ($V$), ponto no qual a corrente resultante é apenas suficiente para vencer o atrito.
\end{itemize}

\subsection{\texorpdfstring{A Equivalência entre $K_T$ e $K_e$}{A Equivalência entre KT e Ke}}

Um dos resultados mais notáveis na teoria de motores é a equivalência numérica entre $K_T$ e $K_e$ quando ambas são expressas em unidades do Sistema Internacional (SI): \textbf{Nm/A} para $K_T$ e \textbf{V·s/rad} para $K_e$.
\begin{equation}
    K_T \text{ [Nm/A]} = K_e \text{ [V·s/rad]}
\end{equation}
Esta equivalência não é uma coincidência, mas uma consequência da \textbf{lei da conservação de energia}.

\textbf{Demonstração por Balanço de Potência:}
\begin{enumerate}
    \item A potência elétrica convertida em potência mecânica ($P_{\text{conv}}$) é a parte da potência de entrada que não é perdida como calor nos enrolamentos.

    \item A potência elétrica fornecida à armadura é
    \begin{equation}
        P_{\text{in}} = V \cdot I_a
    \end{equation}
    Substituindo a equação elétrica $V = e_a + I_a R_a$:
    \begin{equation}
        P_{\text{in}} = (e_a + I_a R_a) I_a = e_a I_a + I_a^2 R_a
    \end{equation}
    A parcela $I_a^2 R_a$ corresponde às perdas Joule nos enrolamentos; descontando-as, a potência eletromecanicamente convertida é
    \begin{equation}
        P_{\text{conv}} = e_a I_a
    \end{equation}

    \item A potência mecânica de saída ($P_{\text{mec}}$) é o produto do torque eletromagnético e da velocidade angular:
    \begin{equation}
        P_{\text{mec}} = T_e \cdot \omega
    \end{equation}

    \item Pela conservação de energia, a potência convertida iguala-se à potência mecânica de saída:
    \begin{equation}
        P_{\text{conv}} = P_{\text{mec}}
    \end{equation}

    \item Combinando os itens anteriores, $P_{\text{conv}} = P_{\text{mec}}$ implica
    \begin{equation}
        e_a I_a = T_e \omega
    \end{equation}
    Substituindo as definições $e_a = K_e \omega$ e $T_e = K_T I_a$:
    \begin{equation}
        (K_e \omega) I_a = (K_T I_a) \omega
    \end{equation}

    \item Para qualquer condição de operação não nula, podemos cancelar $\omega$ e $I_a$ de ambos os lados, provando que:
    \begin{equation}
        K_e = K_T
    \end{equation}
\end{enumerate}
Esta prova revela que o mesmo mecanismo de acoplamento eletromagnético que produz torque a partir da corrente (princípio motor, $K_T$) é o que gera tensão a partir do movimento (princípio gerador, $K_e$). Eles são duas manifestações do mesmo fenômeno físico \parencite{zoltan2012understanding, garcia1997modelagem}.

\subsection{Conversão de Unidades}

A elegância teórica é frequentemente obscurecida pelo uso de unidades inconsistentes na prática. A habilidade de converter valores de folhas de dados para o padrão SI é indispensável. A relação prática mais importante é entre $K_T$ e $K_V$:
\begin{equation}
    K_T \text{ [N·m/A]} = \frac{60 \cdot K_V \text{ [RPM/V]}}{2\pi}
\end{equation}
Esta fórmula é derivada diretamente da equivalência $K_T = K_e = 1/K_V$ após a conversão da velocidade para rad/s \parencite{infineon2011bldc}. A tabela abaixo resume as conversões chave.

\begin{table}[H]
\centering
\caption{Unidades de Constantes de Motor e Fatores de Conversão para o SI}
\label{tab:unidades}

\resizebox{\textwidth}{!}{%
\begin{tabular}{llll}
\toprule
\textbf{Parâmetro} & \textbf{Unidade SI} & \textbf{Unidades Comuns Não-SI} & \textbf{Fórmula de Conversão para SI} \\
\midrule
\textbf{Constante de Torque ($K_T$)} & N·m/A & oz-in/A & 1 oz-in/A = 0.00706155 N·m/A \\
 & & mN·m/A & 1 mN·m/A = 0.001 N·m/A \\
\addlinespace
\textbf{Constante de FCEM ($K_e$)} & V·s/rad & V/krpm & 1 V/krpm = 0.009549 V·s/rad \\
\addlinespace
\textbf{Constante de Velocidade ($K_V$)} & rad/(V·s) & RPM/V & 1 RPM/V = 0.10472 rad/(V·s) \\
\bottomrule
\end{tabular}%
}
\legendafonte{Elaborado pelo autor (2026).}
\end{table}

\subsection{\texorpdfstring{A Constante do Motor ($K_m$) como Figura de Mérito}{A Constante do Motor (Km) como Figura de Mérito}}

Uma constante mais fundamental para avaliar a qualidade do projeto de um motor é a \textbf{constante do motor ($K_m$)}:
\begin{equation}
    K_m = \frac{K_T}{\sqrt{R_a}}
\end{equation}
Sua unidade no SI é \textbf{N·m/$\sqrt{\text{W}}$}. $K_m$ representa a capacidade do motor de produzir torque por watt de potência dissipada como calor. Um $K_m$ mais alto indica um motor com maior rendimento na conversão de energia. Notavelmente, $K_m$ é invariante a alterações no enrolamento para um mesmo tamanho de carcaça, tornando-se uma excelente figura de mérito para comparar a qualidade de diferentes projetos de motores \parencite{infineon2011bldc}.

\subsection{Influência da Temperatura}

Embora chamadas de "constantes", $K_T$ e $K_e$ são afetadas pela temperatura. O aquecimento do motor causa uma redução na força magnética dos ímãs permanentes. Como ambas as constantes são diretamente proporcionais à densidade de fluxo magnético, um motor operando em alta temperatura produzirá menos torque para a mesma corrente (menor $K_T$) e precisará girar mais rápido para gerar a mesma FCEM (menor $K_e$, consequentemente um $K_V$ ligeiramente maior), resultando em uma performance geral degradada.

\section{Controlador Eletrônico de Velocidade (ESC)} 
 Os controladores eletrônicos de velocidade, são dispositivos eletrônicos que controlam a velocidade e o torque de motores BLDC. São classificados pela sua corrente e tensão máxima de saída. São constituídos dos seguintes componentes básicos: 

 \begin{itemize} 
 \item Circuito de entrada: O circuito de entrada converte a tensão fornecida pela bateria em tensão que pode ser usada pelo circuito de controle utilizando PWM para gerar uma tensão média desejada que será fornecida ao motor. Também pode inverter a sequência de comutação das fases fazendo com que o sentido de rotação também seja invertido. 
 \item Circuito de controle: O circuito de controle é responsável por calcular a corrente que deve ser fornecida às bobinas do motor. Normalmente se utilizam de sinais com características de PWM como sinal de referência para definir a velocidade e sentido de rotação. 
 \item Circuito de saída: O circuito de saída fornece a corrente necessária às bobinas do motor. 
 \end{itemize} 

 Além desses componentes básicos, os ESCs para motor BLDC pode incluir os seguintes recursos, além dos já discutidos anteriormente: 

 \begin{itemize} 
 \item Filtro de ruído: O filtro de ruído é usado para reduzir o ruído elétrico que pode ser gerado pelo motor. 
 \item Proteção térmica: A proteção térmica é usada para proteger o motor de superaquecimento. 
 \item Proteção contra sobrecarga: O ESC pode desligar o motor se ele experimentar correntes superiores às nominais que representam riscos de deterioração das bobinas do motor. 
 \end{itemize} 

  As equações lineares de um motor DC só são diretamente aplicáveis a um motor BLDC devido à ação sofisticada do seu \textbf{Controlador Eletrônico de Velocidade (ESC)}. O ESC realiza a comutação eletrônica, energizando sequencialmente os enrolamentos do estator para criar um campo magnético giratório. Isso força a complexa máquina AC a se comportar como o motor DC idealizado, tornando as constantes $K_T$ e $K_e$ ferramentas de análise e projeto perfeitamente válidas \parencite{hendershot1994design}.

 \subsection{\texorpdfstring{Consequências Práticas da Seleção de $K_V$}{Consequências Práticas da Seleção de KV}} 

 A seleção de $K_V$ é uma decisão de projeto crítica que estabelece um compromisso fundamental: 
 \begin{itemize} 
 \item \textbf{Motores de Alto $K_V$:} Possuem menos espiras de fio mais grosso. Resultam em baixo $K_T$, baixa resistência e baixa indutância. Para produzir torque, exigem alta corrente, mas atingem altas velocidades. Ideais para aplicações de alta velocidade e baixo torque, como drones de corrida e fusos de usinagem \parencite{tmotor2019kv}. 
 \item \textbf{Motores de Baixo $K_V$:} Possuem mais espiras de fio mais fino. Resultam em alto $K_T$, alta resistência e alta indutância. Geram alto torque com baixas correntes, apresentando maior rendimento para essa finalidade, mas com menor velocidade máxima. Ideais para aplicações de acionamento direto e alto torque, como drones de carga, guinchos e atuadores robóticos \parencite{byod2018kv}. 
 \end{itemize} 

 \subsection{Princípios de Operação} 

 O controlador eletrônico tem a função de fornecer tensão e corrente adequadas às bobinas do estator, visando o controle preciso da velocidade e do torque da máquina \cite{jahns1996pulsating}. A topologia fundamental para esta finalidade é a ponte inversora trifásica, à qual o motor BLDC pode ser acoplado em configuração estrela ou triângulo. O chaveamento dos transistores do inversor deve ser orquestrado de forma que cada fase seja percorrida por uma corrente com forma de onda senoidal ou trapezoidal. A excitação senoidal é voltada para um acionamento de alto desempenho e suavidade, enquanto a trapezoidal destaca-se pela simplicidade de controle e baixo custo de implementação. Para garantir a geração de um campo magnético girante e a rotação contínua do rotor, as formas de onda das três fases devem ser defasadas em 120 graus elétricos entre si.

 \subsubsection{Comutação de Seis Passos} 

 A comutação de seis passos demanda um sincronismo de disparo dos transistores de modo que, no modelo ideal, sempre dois deles estejam fechados: um transistor do lado superior (\textit{high-side}) conectado ao barramento positivo e um transistor do lado inferior (\textit{low-side}) conectado ao barramento negativo. Assim, em cada setor de $60^\circ$ elétricos, duas fases são energizadas e a terceira permanece eletricamente aberta para que sua FCEM possa ser observada (Figura \ref{fig:sequencia-acionamento-bldc}). Cada transistor permanece em condução durante $120^\circ$ elétricos.

 A denominação ``seis passos'', entretanto, descreve apenas os seis estados estacionários comandados pelo controlador ao longo de um ciclo elétrico. Do ponto de vista físico da corrente, cada passagem entre dois setores contém também um intervalo transitório de comutação. Portanto, uma descrição mais completa pode ser entendida como doze subintervalos por ciclo elétrico: seis intervalos de condução principal, nos quais a corrente percorre duas fases, e seis intervalos de transferência, nos quais a corrente da fase que está sendo desligada ainda precisa encontrar um caminho de circulação.

 Esse comportamento ocorre porque os enrolamentos do estator são indutivos. A corrente de um elemento indutivo não pode variar instantaneamente, logo, quando um MOSFET é bloqueado, a corrente que circulava naquela fase não desaparece. Ela força a tensão do terminal da fase a se deslocar até polarizar diretamente o diodo de corpo de algum MOSFET. A corrente que estava circulando pela fase de saída continua fluindo pelo enrolamento da fase de saída e é desviada para um caminho de roda livre formado pelos diodos intrínsecos dos MOSFETs, até que sua energia magnética seja transferida para a outra fase.

 Considere, por exemplo, a transição do setor $A^+B^-$ para o setor $A^+C^-$. Antes da comutação, a corrente principal percorre o caminho $+V_{DC} \rightarrow H_A \rightarrow A \rightarrow B \rightarrow L_B \rightarrow -V_{DC}$, onde $H_A$ representa o transistor superior da fase A e $L_B$ o transistor inferior da fase B. Quando $L_B$ é desligado, a corrente que saía pela fase B continua no mesmo sentido por causa da energia armazenada no indutor. Como o caminho pelo transistor inferior foi aberto, o terminal B é elevado até conduzir pelo diodo de corpo do transistor superior da mesma fase ($H_B$), fechando uma malha de recirculação. Ao mesmo tempo, $L_C$ começa a conduzir e a corrente cresce na nova fase de retorno C. Durante esse intervalo, a corrente se divide entre uma malha antiga em decaimento, associada à fase B, e uma malha nova em crescimento, associada à fase C.

O caso complementar ocorre quando a fase que está saindo é conectada ao terminal positivo do barramento CC. Em uma transição como $A^+C^-$ para $B^+C^-$, o transistor superior de A é bloqueado e a corrente da fase A, que ainda tende a entrar no enrolamento, força o terminal A a conduzir pelo diodo de corpo do transistor inferior de A ($L_A$). Assim, quando um transistor superior é bloqueado, o caminho complementar é formado pelo diodo em antiparalelo do transistor inferior da mesma fase e quando um transistor inferior é bloqueado, o caminho complementar é formado pelo diodo em antiparalelo do transistor superior da mesma fase. A Tabela \ref{tab:subintervalos_comutacao_6step} resume essa sequência para uma rotação elétrica completa.

\begin{table}[H]
\centering
\caption{Estados principais e intervalos transitórios na comutação trapezoidal}
\label{tab:subintervalos_comutacao_6step}
\small
\begin{tabular}{@{}p{1.5cm}p{2.2cm}p{4.3cm}p{5.1cm}@{}}
\toprule
Setor & Estado principal & Caminho principal da corrente & Intervalo de transferência para o próximo setor \\
\midrule
1 & $A^+B^-$ & $+V_{DC} \rightarrow H_A \rightarrow A \rightarrow B \rightarrow L_B \rightarrow -V_{DC}$ & $B$ deixa de ser a fase de retorno; sua corrente decai pelo diodo de $H_B$, enquanto $C$ passa a conduzir por $L_C$. \\
2 & $A^+C^-$ & $+V_{DC} \rightarrow H_A \rightarrow A \rightarrow C \rightarrow L_C \rightarrow -V_{DC}$ & $A$ deixa de ser a fase de alimentação; sua corrente decai pelo diodo de $L_A$, enquanto $B$ passa a conduzir por $H_B$. \\
3 & $B^+C^-$ & $+V_{DC} \rightarrow H_B \rightarrow B \rightarrow C \rightarrow L_C \rightarrow -V_{DC}$ & $C$ deixa de ser a fase de retorno; sua corrente decai pelo diodo de $H_C$, enquanto $A$ passa a conduzir por $L_A$. \\
4 & $B^+A^-$ & $+V_{DC} \rightarrow H_B \rightarrow B \rightarrow A \rightarrow L_A \rightarrow -V_{DC}$ & $B$ deixa de ser a fase de alimentação; sua corrente decai pelo diodo de $L_B$, enquanto $C$ passa a conduzir por $H_C$. \\
5 & $C^+A^-$ & $+V_{DC} \rightarrow H_C \rightarrow C \rightarrow A \rightarrow L_A \rightarrow -V_{DC}$ & $A$ deixa de ser a fase de retorno; sua corrente decai pelo diodo de $H_A$, enquanto $B$ passa a conduzir por $L_B$. \\
6 & $C^+B^-$ & $+V_{DC} \rightarrow H_C \rightarrow C \rightarrow B \rightarrow L_B \rightarrow -V_{DC}$ & $C$ deixa de ser a fase de alimentação; sua corrente decai pelo diodo de $L_C$, enquanto $A$ passa a conduzir por $H_A$. \\
\bottomrule
\end{tabular}
\end{table}

 Dessa forma, o controle é comandado em seis setores, mas a corrente percorre doze situações relevantes: seis caminhos principais de produção de torque e seis caminhos transitórios de roda livre ou regeneração parcial. Durante essas transições, nenhuma fase é instantaneamente desligada em termos eletromagnéticos; a fase de saída permanece conduzindo por diodo por uma fração do período, enquanto a fase de entrada ainda está estabelecendo corrente. A consequente distorção transitória das tensões de fase e a assimetria entre a corrente que decai e a corrente que cresce são as principais causas das oscilações no torque do motor (\textit{torque ripple}) características deste método \cite{kim2017electric, jahns1996pulsating}.
 
 Esse algoritmo de acionamento dos transistores, também chamado de Controle Trapezoidal, é a base para o funcionamento do motor BLDC. Embora seja possível operá-lo em malha aberta (sequência fixa), esta abordagem apresenta baixo rendimento e é propensa à perda de sincronismo sob variações de carga. Portanto, neste trabalho, projeta-se e implementa-se a infraestrutura de \textit{hardware} e \textit{firmware} para um \textbf{ESC trapezoidal \textit{sensorless}}, incluindo os circuitos de reconstrução de neutro virtual, filtragem RC e comparadores LM339 destinados à detecção de cruzamento por zero (ZCD) da FCEM. 
 
 \begin{figure}[H]
    \centering
    \caption{Sequência de acionamento para um BLDC trifásico.}
    
    \legendafonte{\cite{kim2017electric}.}
    \label{fig:sequencia-acionamento-bldc}
\end{figure}

 Nesta etapa de validação, a comutação opera em \textbf{malha aberta} (alinhamento e rampa forçada); a \textbf{transição para comutação em malha fechada orientada por ZCD} permanece como passo subsequente, após a confirmação da sequência 6-step e do condicionamento do sinal, conforme detalhado no Capítulo 4.

 Quando a aplicação necessita que o motor possua apenas uma velocidade, a fonte de alimentação de tensão fixa é suficiente. Para casos onde é necessário variar a velocidade do motor, a técnica de Modulação por Largura de Pulso (PWM) é normalmente empregada. Um ESC, por exemplo, utiliza PWM para ajustar a tensão média aplicada ao motor, controlando assim sua velocidade. Essa técnica, no entanto, pode demandar a utilização de controladores que comparem a velocidade desejada com a medida no rotor para um controle preciso, estratégia desenvolvida teoricamente na Seção~\ref{sec:controle_pi}. 

 \subsubsection{Análise da Ondulação de Torque (Torque Ripple)}
A principal desvantagem intrínseca à comutação forçada de seis passos (malha aberta) é a geração de uma ondulação de torque (\textit{torque ripple}), que se manifesta como pulsações no torque de saída do motor \cite{jahns1984torque, ali2017implementation}. Essas pulsações podem causar oscilações na velocidade, ruído acústico e vibrações mecânicas, sendo particularmente prejudiciais em aplicações que exigem alta precisão de movimento \cite{jahns1996pulsating}. A frequência desta ondulação é seis vezes a frequência elétrica fundamental do motor, correspondendo a uma pulsação a cada evento de comutação \cite{jahns1984torque}. Conforme analisado em trabalhos seminais como os de Jahns (1984) e Hendershot \& Miller (1994), este fenômeno é consequência de dois fatores principais \cite{kim2017electric, hendershot1994design}.

\begin{enumerate}
    \item \textbf{Incompatibilidade de Formas de Onda:} O modelo ideal do controle trapezoidal assume uma forma de onda de corrente perfeitamente retangular e uma FCEM perfeitamente trapezoidal. Na prática, a FCEM dos motores reais raramente é um trapézio ideal, e a corrente injetada não é perfeitamente retangular. Qualquer desalinhamento ou incompatibilidade entre a forma de onda da corrente e a da FCEM resulta em variações no torque produzido, conforme a equação $T_{e} = (e_{a} \cdot i_{a} + e_{b} \cdot i_{b} + e_{c} \cdot i_{c}) / \omega$ \cite{hendershot1994design}.

    \item \textbf{Transientes de Comutação:} A causa mais significativa da ondulação de torque é o próprio processo de comutação. Devido à indutância presente nos enrolamentos do motor, a corrente não pode variar instantaneamente. Quando o controlador comuta de um passo para o outro (por exemplo, de A-B para A-C), há um período de tempo finito durante o qual a corrente na fase que está sendo desligada (fase B) decai através do diodo de roda livre, e a corrente na fase que está sendo ligada (fase C) aumenta através da chave ativa \cite{jahns1996pulsating, joice2013compensation}. Durante este intervalo de comutação, o torque eletromagnético total produzido pelo motor não é constante. A taxa de variação da corrente na fase de entrada ($\frac{di_{in}}{dt}$) e na de saída ($\frac{di_{out}}{dt}$) é assimétrica devido à diferença de potencial aplicada em cada malha. Enquanto o crescimento da corrente na fase de entrada é retardado pela oposição da sua Força Contra-Eletromotriz (FCEM), o decaimento da corrente na fase de saída é acelerado pela soma da tensão do barramento com a sua respectiva FCEM durante a condução pelo diodo de roda livre. Essa diferença nas derivadas de corrente gera uma perturbação transitória na soma total das correntes do estator, resultando em um mergulho (\textit{dip}) ou pico de torque a cada $60^{\circ}$ elétricos \cite{choi1998commutation, chen2019commutation}.

\end{enumerate}

A ondulação de torque não é apenas um efeito colateral indesejado; é a manifestação mecânica de uma conversão de energia eletromecânica periodicamente de baixo rendimento. O objetivo do motor é converter potência elétrica em potência mecânica (torque vezes velocidade) de forma contínua e suave. Durante os intervalos de comutação, o vetor de corrente do estator está em transição entre duas posições estáveis. Neste período, o alinhamento entre o campo magnético do estator e o campo magnético do rotor desvia-se momentaneamente da orientação ótima de $90^{\circ}$ elétricos necessária para a produção máxima de torque. Consequentemente, para uma mesma magnitude de corrente de entrada, o torque de saída é reduzido, representando uma queda transitória no rendimento da conversão de energia. A ondulação de torque observada é, portanto, o resultado direto desses intervalos de conversão sub-ótima, inerentes à natureza discreta do chaveamento de seis passos.

\subsubsection{Modulação por Largura de Pulso (PWM)} 

O controle de velocidade e torque de motores BLDC exige a imposição de uma tensão terminal variável nos enrolamentos do estator. Dado que as fontes de alimentação primárias disponíveis na maioria das aplicações (como baterias e fontes de bancada) operam com uma tensão contínua fixa ($V_{DC}$), faz-se necessária a aplicação da técnica de Modulação por Largura de Pulso (PWM, \textit{Pulse Width Modulation}). Esta técnica consiste no chaveamento periódico de alta frequência dos semicondutores de potência da ponte inversora, aplicando pulsos de tensão retangulares de amplitude fixa e largura variável à carga indutiva.

O parâmetro fundamental que rege o comportamento do PWM é a razão cíclica (\textit{duty cycle}, $D$), definida matematicamente como a relação entre o tempo em que o sinal permanece em nível lógico alto ($t_{on}$) e o período total do ciclo de chaveamento ($T$), conforme expresso na Equação \ref{eq:duty_cycle}:

\begin{equation}
D = \frac{t_{on}}{T} = t_{on} \cdot f_c
\label{eq:duty_cycle}
\end{equation}

Em que $f_c$ representa a frequência de portadora ou frequência de chaveamento. A tensão média efetiva entregue aos enrolamentos do estator ($V_{m\text{é}dia}$) é obtida por meio da integração do sinal de tensão instantâneo ao longo de um período completo, resultando em uma relação linear direta com a razão cíclica, explicitada na Equação \ref{eq:v_media}:

\begin{equation}
V_{m\text{é}dia} = \frac{1}{T} \int_{0}^{t_{on}} V_{DC} \, dt = \frac{t_{on}}{T} V_{DC} = D \cdot V_{DC}
\label{eq:v_media}
\end{equation}

A seleção da frequência de chaveamento ($f_c$) constitui um compromisso crítico de projeto de engenharia, governado por restrições de ordem magnética, acústica e térmica. Motores BLDC de alto desempenho e tamanho reduzido comumente apresentam resistência estatórica e indutância de fase extremamente baixas. Sob frequências de chaveamento reduzidas, a baixa constante de tempo indutiva ($\tau = L/R$) resulta em uma elevada ondulação de corrente (\textit{current ripple}), o que culmina em perdas excessivas por efeito Joule no cobre e geração de ruído acústico na faixa audível humana (20 Hz a 20 kHz). 

Por outro lado, a elevação excessiva de $f_c$ acarreta o aumento linear das perdas por comutação (\textit{switching losses}) nos MOSFETs de potência, dadas pela transição periódica entre os estados de condução e bloqueio, conforme modelado simplificadamente na Equação \ref{eq:perdas_comutacao}:

\begin{equation}
P_{sw} = V_{DC} \cdot I_{out} \cdot f_c \cdot \left( \frac{t_r + t_f}{2} \right)
\label{eq:perdas_comutacao}
\end{equation}

Em que $I_{out}$ é a corrente de saída, e $t_r$ e $t_f$ são os tempos de subida (\textit{rise time}) e descida (\textit{fall time}) do transistor, respectivamente. No desenvolvimento de inversores voltados a protótipos de ESC, adota-se rotineiramente uma frequência de portadora de aproximadamente 20 kHz. Esse valor se posiciona no limiar superior da audição humana, mitigando poluição sonora decorrente do magnetostritismo, ao mesmo tempo em que preserva a integridade térmica dos transistores e minimiza a ondulação da corrente contínua através do estator.

No âmbito da comutação trapezoidal de seis passos, o sinal PWM gerado pelo periférico de controle (como o módulo MCPWM) pode ser aplicado de diferentes formas aos braços do inversor trifásico durante o setor de condução de $120^\circ$ elétricos. Destacam-se as seguintes estratégias de modulação unipolar:

\begin{itemize}
    \item \textbf{Estratégia H\_PWM - L\_ON:} O sinal PWM de alta frequência é aplicado exclusivamente ao transistor do lado da alta (\textit{High-Side}), enquanto o dispositivo correspondente do lado da baixa (\textit{Low-Side}) permanece permanentemente conduzindo em nível contínuo (SINK) durante todo o intervalo de $120^\circ$. Esta abordagem reduz sensivelmente as perdas por comutação totais da ponte, uma vez que apenas uma das chaves ativas sofre transições rápidas a cada período.
    \item \textbf{Estratégia H\_ON - L\_PWM:} Configuração inversa à anterior, na qual a chave superior é mantida saturada em nível lógico alto e a chave inferior modula a corrente em alta frequência.
\end{itemize}

Durante os períodos de desligamento do PWM ($t_{off}$) na estratégia H\_PWM - L\_ON, a energia armazenada no campo magnético indutivo da bobina força a circulação da corrente através do diodo de roda livre intrínseco do MOSFET complementar, estabelecendo um circuito de recirculação. A correta temporização e o entendimento de que a largura de pulso atua diretamente na magnetização do estator formam o alicerce para o controle de torque do sistema.

\begin{figure}[H]
    \centering
    \caption{Modulação por largura de pulso utilizando uma fonte de $100V$.}
    
    \legendafonte{\cite{matlabBLDC}.}
    \label{fig:pwm-fonte-100v}
\end{figure}

 \subsection{Estratégia de Partida em Malha Aberta para Operação \textit{Sensorless}}

A implementação de um controle \textit{sensorless} eficaz depende da capacidade do controlador de estimar a posição do rotor a partir de grandezas elétricas, mais comumente a FCEM. Contudo, esta abordagem apresenta um desafio fundamental: em repouso (velocidade zero), não há movimento relativo entre os ímãs do rotor e os enrolamentos do estator, e, portanto, nenhuma FCEM é gerada \cite{ti2013sensorless, nxp2023sensorless}. Nesta condição "cega", o controlador não possui informações sobre a posição angular do rotor, tornando impossível determinar qual par de fases deve ser energizado para iniciar a rotação na direção desejada. Para superar essa limitação, é necessária uma rotina de partida especializada, operando em malha aberta, que força o motor a girar até que uma velocidade suficiente seja atingida para que a FCEM se torne detectável e o controle em malha fechada possa assumir. Este procedimento é universalmente dividido em duas fases sequenciais: alinhamento e comutação forçada.

\subsubsection{Alinhamento do Rotor}

O primeiro passo para uma partida confiável é estabelecer uma posição inicial conhecida para o rotor. A fase de alinhamento realiza isso ao energizar um conjunto específico de enrolamentos do estator com uma corrente contínua (DC) por um período de tempo pré-determinado \cite{ti2022minimizing, nxp2023sensorless}. Por exemplo, o controlador pode aplicar uma tensão positiva à fase C e conectar as fases A e B ao terra \cite{ti2022minimizing}. Esta ação cria um campo magnético estático e fixo no estator. Os ímãs permanentes do rotor, livres para girar, irão se alinhar com este campo para minimizar a relutância magnética do circuito, de forma análoga a uma agulha de bússola se alinhando com o campo magnético terrestre. Ao final deste processo, o rotor estará travado em uma posição angular conhecida e previsível. Os parâmetros críticos que governam esta fase são a duração do alinhamento e a magnitude da corrente de alinhamento \cite{ti2022minimizing}.

 A fase de alinhamento funciona como uma etapa de otimização pré-torque, o seu objetivo primordial é condicionar o sistema para que o primeiro passo de comutação dinâmica gere o máximo torque possível. O maior desafio ao iniciar um motor a partir do repouso é vencer a inércia da carga e o atrito estático, o que exige um impulso de torque inicial elevado. A teoria de motores elétricos, conforme estabelecido na Seção 1.1.1, dita que o torque é maximizado quando o campo magnético do estator está orientado a $90^{\circ}$ elétricos em relação ao campo do rotor. O algoritmo de controle é projetado sabendo a posição final do rotor após o alinhamento. Assim, a primeira combinação de fases a ser energizada na fase seguinte (rampa de aceleração) é escolhida para criar um novo vetor de campo magnético do estator que esteja precisamente na orientação ótima em relação à posição agora conhecida do rotor. Isso garante que o primeiro passo dinâmico produza um torque potente e eficaz, "chutando" o rotor para o movimento e superando as resistências iniciais. Uma duração de alinhamento insuficiente ou uma corrente muito baixa pode resultar em um alinhamento incompleto, levando a um torque inicial fraco e, consequentemente, a uma falha na partida \cite{ti2022minimizing}.

\subsubsection{Comutação Forçada (Rampa de Aceleração)}

Com o rotor devidamente alinhado, o controlador inicia a fase de comutação forçada. Nesta etapa, o sistema opera em malha aberta, comutando as fases em uma sequência predefinida, sem qualquer realimentação da posição do rotor \cite{nxp2023sensorless}. A frequência de comutação não é aplicada abruptamente; em vez disso, ela é aumentada gradualmente a partir de um valor inicial baixo, seguindo um perfil de aceleração pré-programado, conhecido como "curva de partida em malha aberta" (\textit{open-loop starting curve}) \cite{ti2022minimizing}. Esta rampa de aceleração é definida por coeficientes pré-definidos \cite{ti2022minimizing}.

Durante esta fase, o controlador essencialmente comanda a rotação do campo magnético do estator e "assume" que o rotor, devido à sua inércia e ao torque gerado, conseguirá acompanhar este campo giratório. O processo continua, com a frequência de comutação aumentando progressivamente, até que a velocidade de rotação do motor seja alta o suficiente (tipicamente em torno de $5\%$ da velocidade nominal) para que a FCEM gerada nos enrolamentos atinja uma amplitude que possa ser medida de forma confiável \cite{ti2022minimizing, nxp2023sensorless}. Neste ponto, o sistema realiza a transição (\textit{handoff}) do controle em malha aberta para um modo de controle em malha fechada (por exemplo, baseado na detecção de cruzamento por zero da FCEM), que é de maior rendimento e robusto para a operação contínua.

\subsection{Desafios e Limitações da Partida Forçada}

A estratégia de partida em malha aberta não é isenta de desafios e limitações significativas. A sua natureza "cega" a torna vulnerável a variações de carga e a parâmetros não ideais do sistema.

\subsubsection{Análise do Fenômeno de Perda de Sincronismo (Stall)}

O risco mais proeminente do controle em malha aberta é a perda de sincronismo, comumente conhecida como \textit{stall} ou perda de passo. Este fenômeno ocorre quando a aceleração real do rotor não consegue acompanhar a velocidade de rotação do campo magnético do estator imposta pelo controlador. Se o torque de carga aplicado ao eixo do motor, somado à sua própria inércia, for maior que o torque eletromagnético que o motor consegue produzir em um determinado passo, o rotor "perderá o passo" e ficará para trás \cite{nxp2023sensorless}. Isso pode ser causado por uma carga inicial muito elevada ou por uma rampa de aceleração excessivamente agressiva, que aumenta a frequência de comutação mais rápido do que o rotor consegue acelerar \cite{ti2022minimizing}.

Uma vez que o sincronismo é perdido, o alinhamento entre os campos do rotor e do estator se torna desfavorável, e a produção de torque efetivo colapsa. O resultado é um movimento errático, vibrações intensas, ruído audível e, frequentemente, a parada completa do motor, enquanto o controlador continua a injetar corrente nos enrolamentos de forma ineficaz. Este estado pode levar a picos de corrente perigosos para a eletrônica de potência. Por essa razão, o controle em malha aberta é inadequado para aplicações com cargas variáveis ou que exigem alto torque de partida.

\subsubsection{Outros Efeitos Adversos}

Além do risco de perda de passo, a partida forçada apresenta outras desvantagens:

\begin{itemize}
    \item \textbf{Picos de Corrente:} No início da partida, a velocidade do motor é baixa ou nula, o que significa que a FCEM, que normalmente se opõe à tensão de alimentação e limita a corrente, também é baixa ou inexistente. Sem essa oposição, a corrente que flui para os enrolamentos é limitada apenas pela resistência ôhmica e pela tensão aplicada, podendo atingir valores muito elevados se não for cuidadosamente controlada pelo \textit{duty cycle} do PWM. Estes picos de corrente podem estressar a bateria e os componentes da ponte inversora.
    \item \textbf{Vibração e Baixo Rendimento:} Como o controle é feito "às cegas", o alinhamento entre o campo do estator e o rotor durante a rampa de aceleração nunca é perfeito. Este desalinhamento constante é a fonte da ondulação de torque discutida anteriormente, que se manifesta como vibração mecânica e resulta em uma operação de baixo rendimento, onde uma parte da energia elétrica consumida é dissipada em vez de ser convertida em torque útil.
\end{itemize}

É fundamental reiterar que a partida forçada em malha aberta é uma fase transitória e um meio para um fim. É uma estratégia de \textit{bootstrap} projetada exclusivamente para levar o motor de um estado de repouso para uma velocidade operacional mínima, onde métodos de controle em malha fechada, de maior rendimento, precisos e robustos, podem ser ativados para a operação contínua do sistema \cite{ti2022minimizing, nxp2023sensorless}.

\section{Controle Proporcional-Integral em Malhas Fechadas de ESC}
\label{sec:controle_pi}

Além da comutação trapezoidal e da modulação PWM, a operação precisa de um ESC em regime depende de \textbf{malhas de realimentação} que ajustem continuamente a tensão média aplicada ao motor (ou a corrente de fase) de modo a acompanhar referências de corrente ou velocidade impostas pelo operador. Neste trabalho, essa função é desempenhada por controladores \textbf{proporcional-integral (PI)}, algoritmo amplamente adotado em acionamentos de motores BLDC e PMSM por combinar simplicidade de implementação, robustez frente a perturbações de carga e capacidade de eliminar erro estacionário \cite{krishnan2010permanent, xia2012permanent, kim2017electric}.

\subsection{Distinção entre Malhas de Comutação e Malhas PI}
\label{subsec:distincao_malhas}

Um ESC trifásico opera com \textbf{duas camadas de controle independentes}, que não devem ser confundidas. A primeira decide \textit{quando} comutar as fases (sincronismo angular com o rotor); a segunda decide \textit{quanto} esforço elétrico aplicar em cada passo (corrente ou velocidade desejada). A nomenclatura ``malha aberta'' e ``malha fechada'' aplica-se separadamente a cada camada, e não ao sistema como um todo.

\begin{table}[H]
\centering
\caption{Duas camadas de controle no ESC deste trabalho}
\label{tab:camadas_controle}
\resizebox{\textwidth}{!}{%
\begin{tabular}{p{3.2cm}p{4.8cm}p{3.2cm}p{3.8cm}}
\toprule
\textbf{Camada} & \textbf{Grandeza regulada} & \textbf{Realimentação} & \textbf{Estado neste projeto} \\
\midrule
Comutação 6-step & Instante de troca de fase (posição do rotor) & FCEM/ZCD ou temporizador & Malha \textbf{aberta} na validação atual (rampa por temporizador; ver Subseções anteriores deste capítulo) \\
Malha PI & Corrente de fase e/ou velocidade & INA240 + ADC1; intervalo entre passos & Malha \textbf{fechada} sempre que o PI está ativo \\
\bottomrule
\end{tabular}%
}
\legendafonte{Elaborado pelo autor (2026).}
\end{table}

Três esclarecimentos estruturam o uso desses termos ao longo deste trabalho:

\begin{enumerate}
    \item \textbf{O controlador PI é malha fechada, e não aberta.} Por definição, o PI exige comparar referência $r$ com medição $y$ (Equação~\ref{eq:pi_continuo} adiante). No firmware, a corrente de fase é medida pelos amplificadores INA240 e convertida pelo ADC1; no modo velocidade, a velocidade é estimada a partir do intervalo entre passos de comutação. Sem essa realimentação, não haveria erro $e = r - y$ nem termo integral, tratar-se-ia apenas de um \textit{duty cycle} fixo ou de uma rampa pré-programada, o que não caracteriza um regulador PI.
    \item \textbf{O sistema ESC como um todo não é inteiramente malha fechada.} Na fase de validação descrita neste trabalho, a comutação trapezoidal avança em \textbf{malha aberta}: a sequência 6-step progride por temporizador (rampa de frequência elétrica), sem usar o cruzamento por zero da FCEM para sincronizar o rotor. A infraestrutura de \textit{hardware} para comutação em malha fechada por ZCD (comparadores LM339, neutro virtual) está projetada, mas o \textit{handover} para essa modalidade permanece como etapa subsequente (Subseção anterior sobre comutação \textit{sensorless} e Capítulo de Resultados). Enquanto isso, as malhas PI de corrente e velocidade operam em paralelo, em malha fechada, regulando o esforço elétrico dentro de cada passo comutado.
    \item \textbf{Onde cada conceito é tratado neste texto.} A comutação e a partida em malha aberta alinhamento, rampa forçada, risco de \textit{stall} e transição futura para ZCD, são desenvolvidas na Seção anterior (Controlador Eletrônico de Velocidade). A presente seção trata exclusivamente das malhas PI em malha fechada (corrente e velocidade). A implementação no firmware, ganhos $K_p$ e $K_i$, e os resultados de bancada encontram-se nos Capítulos de Metodologia e de Resultados e Discussão.
\end{enumerate}

\subsection{Fundamentos do Controlador PI}

Em uma malha fechada, o controlador recebe uma \textbf{referência} $r$ (por exemplo, corrente ou velocidade desejada) e compara-a com a \textbf{medição} $y$ proveniente dos sensores. O \textbf{erro} instantâneo é definido como:
\begin{equation}
    e(t) = r - y(t)
\end{equation}
A ação de controle $u(t)$ combina uma resposta proporcional ao erro atual e uma resposta integral que acumula o erro ao longo do tempo:
\begin{equation}
    u(t) = K_p \, e(t) + K_i \int_0^t e(\tau) \, d\tau
    \label{eq:pi_continuo}
\end{equation}
onde $K_p$ é o ganho proporcional e $K_i$ o ganho integral. O termo proporcional confere resposta imediata a desvios; o termo integral corrige desvios persistentes, pois continua a agir enquanto $e(t) \neq 0$.
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

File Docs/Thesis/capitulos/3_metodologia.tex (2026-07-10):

\chapter{Metodologia}
O desenvolvimento do ESC será realizado seguindo uma abordagem de engenharia de sistemas, partindo da especificação da carga e fonte de energia, passando pelo dimensionamento dos estágios de potência e controle, e finalizando com a validação experimental. A metodologia está estruturada em: definição da arquitetura do sistema, dimensionamento do hardware de potência, simulação computacional e, por fim, a montagem, prototipagem e
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

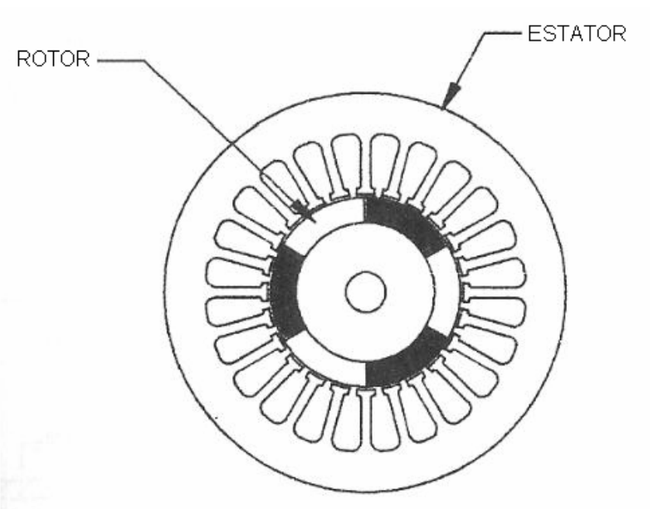
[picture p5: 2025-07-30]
Docs/Thesis/imagens/inrunner.png

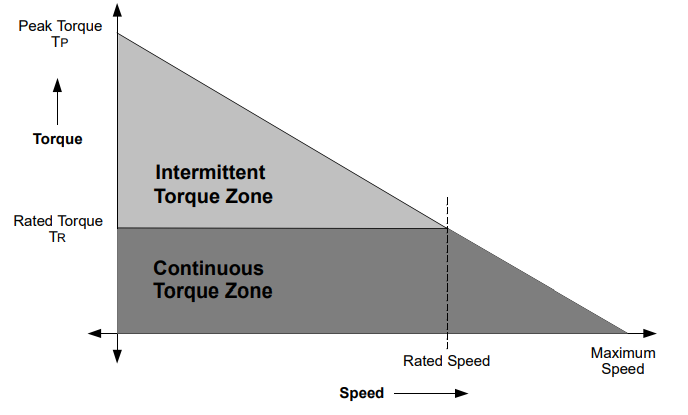
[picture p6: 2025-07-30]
Docs/Thesis Plan/imagens/relação torque e velocidade.png

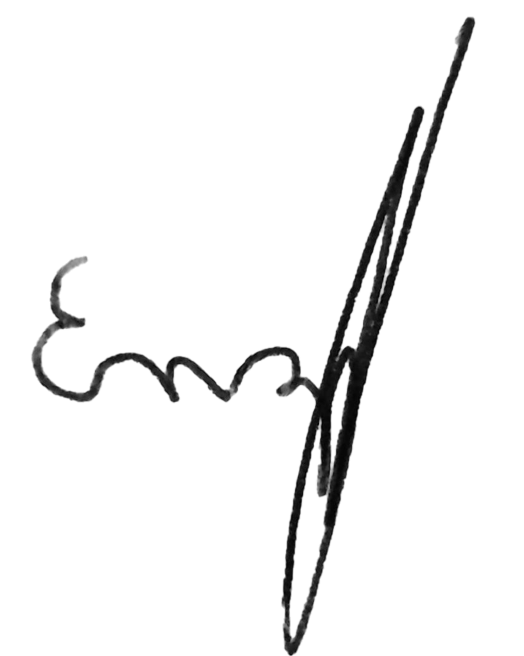
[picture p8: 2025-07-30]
Docs/Thesis/imagens/Assinatura.png

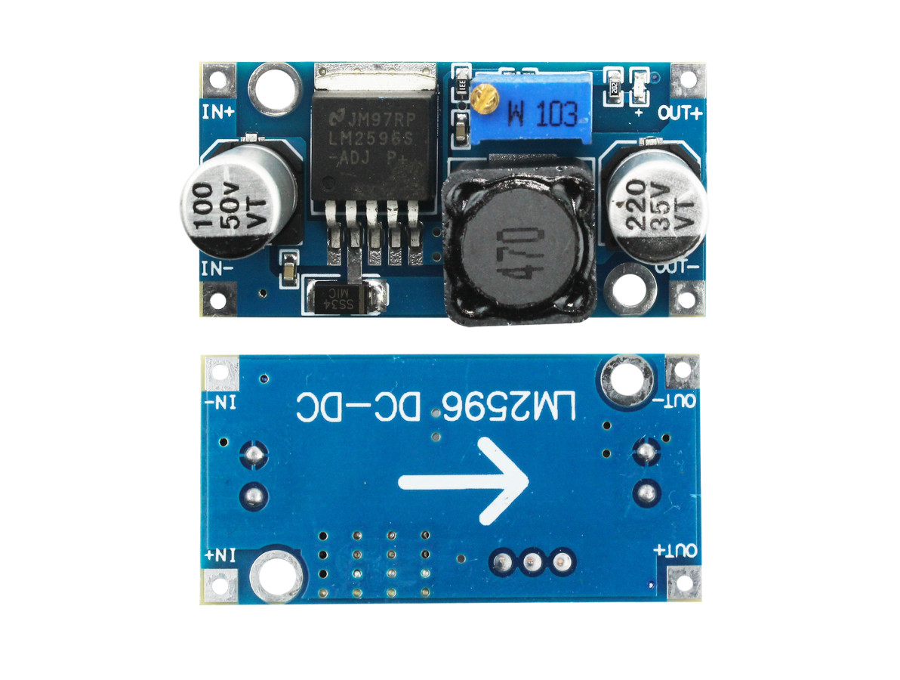
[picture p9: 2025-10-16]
Docs/Thesis/imagens/Módulo LM2596.jpg

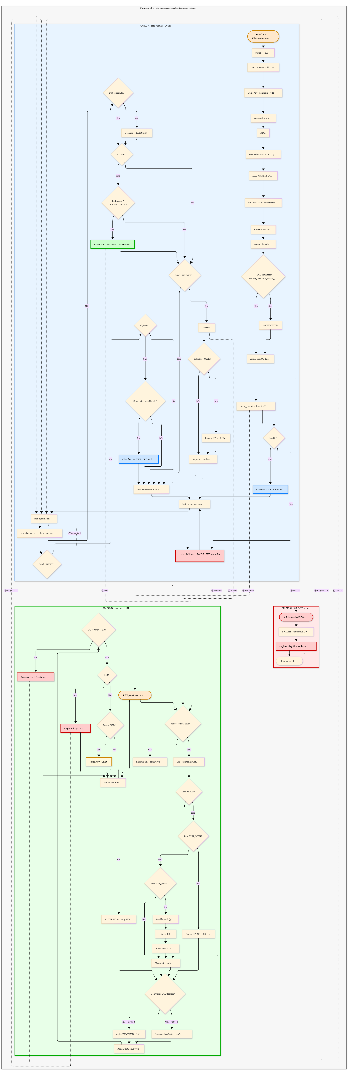
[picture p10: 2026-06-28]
Docs/Thesis/imagens/Fluxograma - Completo.png

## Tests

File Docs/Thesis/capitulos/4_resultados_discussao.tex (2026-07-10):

\chapter{Resultados e Discussão}

Este capítulo apresenta exclusivamente os resultados obtidos na execução do projeto: validação computacional por simulação, análise dos esquemáticos e da PCB protótipo, verificação da arquitetura de firmware (máquina de estados, correção do domínio RTC GPIO nos pinos \textit{Shutdown} dos IR2110, malha de controle a $1\,\text{kHz}$) e ensaios de bancada com energização incremental. O ensaio a vazio documentou falha estrutural no estágio de potência, inviabilizando a continuidade do protocolo de validação dinâmica com motor em rotação, cujo planejamento encontra-se na Subseção~\ref{subsec:protocolo_validacao_proposto} do Capítulo de Metodologia.

\section{Validação Computacional (Simulação)}

Para a validação conceitual do hardware de potência antes da montagem física, utilizou-se o software \textbf{LTSpice}. A simulação concentrou-se no estágio de potência do inversor, modelando as chaves semicondutoras e a carga indutiva. Foram elaborados dois cenários de simulação: uma topologia monofásica (meia-ponte) para análise isolada e uma topologia trifásica completa para validação do fluxo de corrente inter-fases (Figura \ref{fig:simulacao_trifasica}). Os esquemáticos e curvas de resultado em \texttt{Simulation/} estão disponíveis no repositório~\cite{esp32BldcEscRepo}.

\begin{figure}[H]
    \centering
    \caption{Esquemático da simulação trifásica do ESC em estado estático de comutação.}
    
    \legendafonte{Elaborado pelo autor (2026).}
    \label{fig:simulacao_trifasica}
\end{figure}

O circuito é dividido em três blocos funcionais: alimentação, comutação e carga. A fonte de energia primária é modelada por uma fonte DC de $22,2 \: V$ com uma resistência série ($R_{ser}$) de $19 \: m\Omega$, emulando com precisão a dinâmica de descarga e as perdas ôhmicas internas da bateria LiPo 6S definida para o projeto. O estágio de comutação é composto por uma ponte inversora trifásica utilizando transistores MOSFET (modelo comportamental BSC028N06LS3). As portas (\textit{gates}) destes semicondutores são excitadas através de resistores de $10 \: \Omega$, valor projetado para limitar a corrente de pico do \textit{driver} e amortecer ressonâncias (\textit{ringing}) parasitas sem degradar o tempo de comutação. O acionamento através dos \textbf{drivers de gate} foram modeladas utilizando fontes de tensão do tipo pulso. O sinal de acionamento do lado alto (\textit{High-Side}) da Fase A foi definido com os parâmetros \texttt{PULSE(0 15 0 100n 100n 25u 50u)}, forçando a condução do Passo 1 da sequência trapezoidal. Este perfil injeta um sinal com amplitude de $15\text{V}$, estabelecendo uma frequência de chaveamento de \textbf{$20\text{ kHz}$} (período de $50 \mu\text{s}$) e um ciclo de trabalho (\textit{Duty Cycle}) de \textbf{$50\%$}. Os tempos de transição de subida e descida foram definidos em $100\text{ ns}$ para simular o tempo de resposta do gate do \textbf{MOSFET}.

Por fim, o motor BLDC é representado por seu modelo elétrico equivalente de estator, consistindo em três ramos conectados em estrela (neutro comum). Cada fase possui uma resistência de armadura corrigida de $10 \: m\Omega$ em série com uma indutância de $20 \: \mu H$. Esta modelagem a rotor bloqueado força o sistema a operar sob a condição mais severa de estresse elétrico, permitindo avaliar a capacidade máxima de condução de corrente dos transistores e a resposta transitória da rede indutiva sem a oposição da Força Contraeletromotriz (FCEM), garantindo que os resultados da simulação representem o limite operacional do \textit{hardware}. 

Como o esquemático foca na validação da transferência de energia em um instante específico da \textbf{comutação de seis passos} (Fase A injetando corrente e Fase B drenando para o terra), o transistor do lado baixo da Fase A foi mantido em \textbf{corte} ($0\text{V}$ constante). Devido a esta modelagem estática de um único passo, a inserção de um \textbf{tempo morto ($t_{dead}$)} dinâmico não se fez necessária no gerador de pulsos, assumindo-se o isolamento ideal entre os estados de condução. O motor foi adequadamente modelado na condição de \textbf{rotor bloqueado}, respeitando os parâmetros intrínsecos de resistência ($R = 10m \Omega$) e indutância ($L = 20 \mu\text{H}$) por fase.

A Figura \ref{fig:sim_correntes_motor} apresenta os resultados transitórios das correntes de fase ($I_A$, $I_B$ e $I_C$) durante os dois primeiros ciclos de chaveamento do inversor, totalizando $100 \: \mu s$. Observa-se que, durante o primeiro tempo de condução ($T_{on}$) do sinal PWM entre $0$ e $25 \: \mu s$, a corrente $I_A$ ascende de forma linear até atingir o patamar de aproximadamente $13,5 \: A$. Simultaneamente, a corrente $I_B$ apresenta a mesma magnitude, porém com polaridade invertida ($-13,5 \: A$), enquanto a corrente $I_C$ permanece nula, oscilando apenas com os ruídos numéricos do simulador próximos a zero. Durante o tempo de bloqueio do PWM ($T_{off}$) entre $25 \: \mu s$ e $50 \: \mu s$, as correntes $I_A$ e $I_B$ não caem abruptamente para zero, mas sim sofrem um decaimento suave. O ciclo se repete aos $50 \: \mu s$, elevando as correntes ao patamar de $26 \: A$.

Este comportamento é a resposta direta da excitação do circuito indutivo do estator sob a topologia de modulação \textit{High-Side PWM / Low-Side ON}. Ao disparar o transistor superior da fase A e manter o transistor inferior da fase B em condução plena, estabelece-se um fluxo de elétrons que obrigatoriamente passa por duas bobinas em série ($V = L_{eq} \cdot \frac{di}{dt} + R_{eq} \cdot i$). A inclinação constante ($di/dt$) da rampa de corrente é ditada pela reatância indutiva nominal do motor. Durante o ciclo $T_{off}$ da chave superior, a energia magnética armazenada na indutância do estator força a manutenção do fluxo de corrente, que encontra caminho através do diodo de roda livre (\textit{freewheeling diodo}) intrínseco ao MOSFET inferior da fase A, justificando a lenta taxa de decaimento observada.

\begin{figure}[H]
    \centering
    \caption{Dinâmica das correntes de fase do motor durante os primeiros $100 \: \mu s$ de simulação (Passo 1).}
    
    \legendafonte{Elaborado pelo autor (2026).}
    \label{fig:sim_correntes_motor}
\end{figure}

Ao compararmos com o arcabouço teórico, o resultado valida a comutação de seis passos apresentada na Tabela \ref{tab:mcpwm_map}. A frequência estabelecida pelo projeto de $20 \: kHz$ é ratificada pelo período exato de $50 \: \mu s$ entre os picos de chaveamento valor não arbitrário, mas coerente com o \textit{trade-off} entre perdas térmicas, conforto acústico e \textit{ripple} de corrente fundamentado na Subseção~\ref{subsec:freq_chaveamento_pwm} e dimensionado quantitativamente na Subseção~\ref{subsec:determinacao_fsw}. Mais importante ainda, a completa inércia da fase C ($I_C \approx 0 \: A$) confirma a eficácia do estado de alta impedância (Hi-Z) no braço inversor não excitado, condição \textit{sine qua non} para a medição livre de distorções da Força Contraeletromotriz (FCEM) na posterior transição para a malha fechada.

A Figura \ref{fig:sim_tensoes_neutro} ilustra o comportamento dinâmico das tensões de fase referenciadas ao ponto neutro da carga ($V_{AN}$, $V_{BN}$ e $V_{CN}$). Durante o período de condução do PWM ($T_{on}$), nota-se que o eixo de oscilação das tensões se estabelece em médias de $+11,1 \: V$ para a fase A, $-11,1 \: V$ para a fase B, e $0 \: V$ para a fase C. A severa oscilação de alta frequência (\textit{ringing}) sobreposta aos sinais é um artefato numérico característico do ambiente de simulação. Como a fase C está em estado de alta impedância (flutuante) e o modelo utiliza indutores puros, forma-se um tanque LC não amortecido com as capacitâncias parasitas do transistor, fenômeno que no circuito físico real seria drasticamente atenuado pelas perdas no núcleo ferromagnético do motor e pelo filtro RC do circuito de leitura.

\begin{figure}[H]
    \centering
    \caption{Tensões de fase em relação ao ponto neutro do motor durante o Passo 1.}
    
    \legendafonte{Elaborado pelo autor (2026).}
    \label{fig:sim_tensoes_neutro}
\end{figure}

Do ponto de vista físico, o estabelecimento das tensões em $\pm 11,1 \: V$ é o resultado direto da divisão de potencial no fechamento em estrela (Y) do estator. Com a fase A submetida à tensão plena do barramento ($V_{DC} = 22,2 \: V$) e a fase B conectada ao referencial zero ($0 \: V$), o nó central (neutro) assume naturalmente o potencial médio exato de $11,1 \: V$. Ensaios paralelos nas Fases B e C confirmaram a manutenção do transístor inferior em condução plena ($15 \: V$) e os transistores da fase flutuante em corte ($0 \: V$), atestando a robustez da topologia contra disparos espúrios.

Comparando este resultado com os fundamentos da comutação trapezoidal detalhados na metodologia, a simulação valida a correta formação e estabilidade do potencial de neutro. Esta validação teórica prévia é de suma importância, pois ratifica a viabilidade da técnica de reconstrução de neutro virtual adotada no \textit{hardware}, assegurando que o microcontrolador possuirá uma referência de tensão simétrica e confiável para a detecção da Força Contraeletromotriz (FCEM) durante a operação em malha fechada.

A Figura \ref{fig:sim_bateria_nominal} demonstra o comportamento macro e o esforço contínuo imposto à fonte de alimentação primária (bateria LiPo) quando conectada diretamente à ponte inversora, sem o auxílio do banco de capacitores de barramento (\textit{Link DC}). Observa-se como fato primário que, durante o \textbf{tempo de condução ($T_{on}$)}, a tensão da bateria decai gradualmente de 22,2 V para aproximadamente 21,9 V, conforme ilustrado na Figura \ref{fig:bateria_tensao_nom}. Esse comportamento acompanha a rampa de subida da corrente, que atinge o patamar de 13 A. Durante o \textbf{tempo de bloqueio ($T_{off}$)}, a corrente da bateria cessa completamente, pois a corrente do motor passa a circular em roda livre pelos diodos da ponte.

\begin{figure}[H]
    \centering
    \captionsetup[subfigure]{justification=centering}
    \caption{Análise dinâmica dos parâmetros de entrada da bateria LiPo (escala ajustada): (a) Tensão nominal; (b) Rampa de corrente contínua.}
    \label{fig:sim_bateria_nominal}
    
    \begin{subfigure}[b]{0.49\textwidth}
        \centering
        
        \caption{Tensão de barramento.}
        \label{fig:bateria_tensao_nom}
    \end{subfigure}
    \hfill
    \begin{subfigure}[b]{0.49\textwidth}
        \centering
        
        \caption{Corrente drenada.}
        \label{fig:bateria_corrente_nom}
    \end{subfigure}
    \legendafonte{Elaborado pelo autor (2026).}
\end{figure}

O fator mais crítico e destrutivo, no entanto, é revelado ao observar a escala completa do ensaio. Nos instantes exatos de comutação (50 $\mu$s e 100 $\mu$s), a ponte inversora drena picos agudos de corrente que ultrapassam 130 A e 200 A, respectivamente, como detalhado na Figura \ref{fig:bateria_corrente_trans}. Esses picos provocam quedas instantâneas (\textit{voltage sags}) severas na tensão da bateria, reduzindo-a para níveis próximos a 19,5 V, conforme ilustrado na Figura \ref{fig:bateria_tensao_trans}.

\begin{figure}[H]
    \centering
    \captionsetup[subfigure]{justification=centering}
    \caption{Detalhamento do estresse transiente sobre a bateria LiPo: (a) Quedas instantâneas de tensão (\textit{voltage sags}); (b) Picos transientes de corrente de comutação.}
    \label{fig:sim_bateria_transiente}
    
    \begin{subfigure}[b]{0.49\textwidth}
        \centering
        
        \caption{Tensão de barramento (transientes).}
        \label{fig:bateria_tensao_trans}
    \end{subfigure}
    \hfill
    \begin{subfigure}[b]{0.49\textwidth}
        \centering
        
        \caption{Picos de corrente.}
        \label{fig:bateria_corrente_trans}
    \end{subfigure}
    \legendafonte{Elaborado pelo autor (2026).}
\end{figure}

A causa física para o decaimento gradual da tensão nominal é a queda de potencial ôhmica intrínseca ($V_{drop} = I_a \cdot R_{ser}$) sobre a \textbf{resistência série equivalente} da bateria, que no modelo foi parametrizada como 19 m$\Omega$. Por outro lado, os transientes agudos (\textit{spikes}) de corrente são consequência da elevadíssima taxa de variação ($di/dt$) exigida para carregar as capacitâncias parasitas dos MOSFETs e suprir a corrente de recuperação reversa (\textit{reverse recovery}) dos diodos corporais nos instantes de ativação (\textit{turn-on}). Como o circuito simulado neste ensaio possui apenas a bateria como fonte de energia, ela é forçada a fornecer instantaneamente toda a carga transitória.

A comparação deste comportamento simulado com a teoria de eletrônica de potência embasa o dimensionamento estabelecido na Metodologia. A simulação prova que submeter uma bateria LiPo a este nível de corrente de ondulação (\textit{ripple}) e picos transientes resultaria em superaquecimento severo e degradação química prematura das células. Fica, portanto, validada a necessidade imperativa da instalação do banco de \textbf{capacitores de filtro Low-ESR} (940 $\mu$F) projetado fisicamente na placa de circuito impresso (PCB), cuja função será atuar como um reservatório local de energia de baixíssima impedância para absorver estes transientes de alta frequência, isolando e protegendo a fonte primária.

\section{Projeto Eletrônico e Análise dos Esquemáticos}

Esta seção transita da validação computacional para o hardware físico do protótipo, confrontando o dimensionamento descrito na Metodologia com os esquemáticos finais e o layout da PCB. Os arquivos de esquemático e layout em \texttt{Hardware/PCB\_Project/} encontram-se no repositório~\cite{esp32BldcEscRepo}. A análise percorre, em sequência, a alimentação auxiliar e o barramento DC, o núcleo de controle (ESP32 e drivers IR2110), o condicionamento de sinais e as proteções analógicas, o estágio de potência com MOSFETs e, por fim, as escolhas de roteamento e montagem que condicionaram os ensaios de bancada documentados adiante.

\subsection{Circuito de Alimentação Auxiliar e Regulação}

A Figura \ref{fig:esquematico_supply} detalha a arquitetura de entrada e distribuição de energia do ESC. A conexão primária é realizada através de um conector de alta capacidade XT90, protegida imediatamente em série por um \textbf{fusível MIDI} de $80 \: A$ (modelo 0498080.M). O barramento DC (\textit{Link DC}) é suportado por um banco de capacitores híbrido em topologia paralela, composto por seis capacitores polarizados de $220 \: \mu F$ e três capacitores cerâmicos não polarizados de $1 \: \mu F$. A partir deste barramento filtrado, a tensão nominal da bateria alimenta dois módulos conversores \textit{buck} LM2596 dispostos em paralelo, responsáveis por gerar as malhas de tensão independentes de $15 \: V$ (\textit{Vcc 1}) e $5 \: V$ (\textit{Vcc 2}). Adicionalmente, o esquemático implementa uma separação explícita entre o \textbf{terra de potência (PGND)} e o \textbf{terra de sinal (SGND)}, interligados fisicamente por RJ1.

Fisicamente, a divisão do banco capacitivo em múltiplas unidades de $220 \: \mu F$ reduz drasticamente a \textbf{Resistência Série Equivalente (ESR)} total do barramento, otimizando a absorção da elevada corrente de ondulação (\textit{ripple}) gerada pela ponte inversora sem causar aquecimento excessivo nos componentes. Os capacitores cerâmicos de $1 \: \mu F$ atuam no desacoplamento de alta frequência, suprimindo transientes que os capacitores eletrolíticos não conseguem filtrar devido à sua \textbf{Indutância Série Equivalente (ESL)}. A separação galvânica e o controle de retorno por meio da junção estrita entre \textbf{PGND} e \textbf{SGND} (\textit{Star Grounding}) impedem que as severas correntes de comutação do motor provoquem flutuações de tensão (\textit{ground bounce}) no referencial sensível do microcontrolador. 

\begin{figure}[H]
    \centering
    \caption{Esquemático do estágio de entrada, filtragem do barramento DC e regulação de tensão auxiliar (Folha \textit{Supply}).}
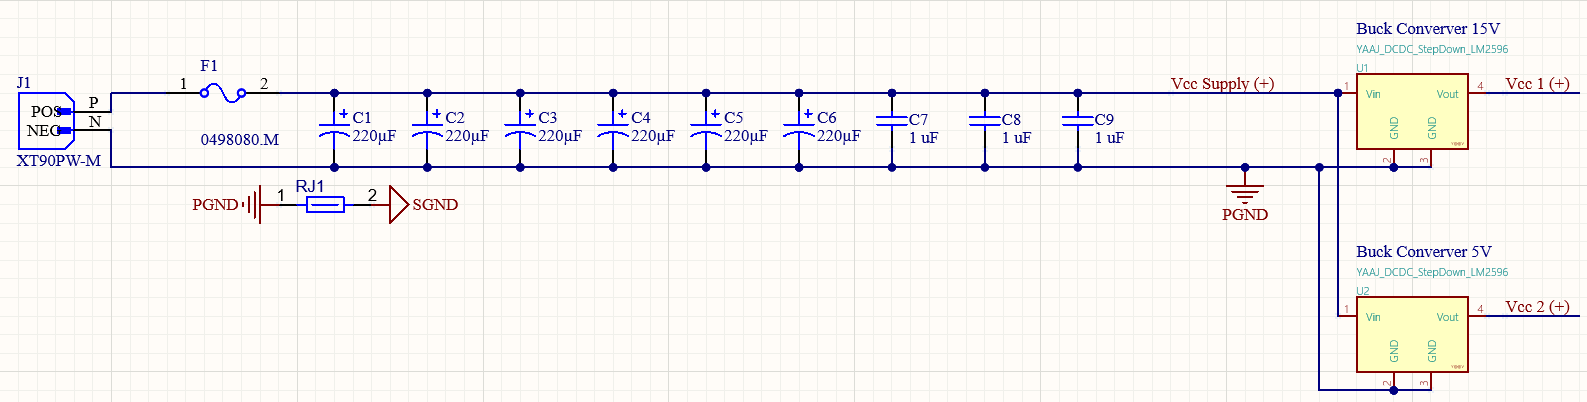
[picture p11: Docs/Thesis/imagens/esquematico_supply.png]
    
    \legendafonte{Elaborado pelo autor (2026).}
    \label{fig:esquematico_supply}
\end{figure}

A comparação sistemática entre os valores dimensionados na Metodologia e os componentes implementados no esquemático final revela quatro divergências intencionais, cada uma motivada por razões técnicas ou pela disponibilidade comercial dos componentes.

A primeira divergência refere-se ao \textbf{fusível de proteção}. O dimensionamento preliminar havia estabelecido um fusível MIDI de $100 \: A$, valor calculado com uma margem de ${\approx}10\,\%$ sobre a corrente de pico estimada de $90 \: A$. O projeto final adota o modelo MIDI $80 \: A$ (0498080.M). A justificativa baseia-se na característica temporal dos fusíveis: ao contrário de chaves eletrônicas, um fusível MIDI não atua de forma instantânea ao cruzar sua corrente nominal, sua curva de tempo-corrente (\textit{time-current curve}) permite suportar $125\,\%$ do valor nominal (i.e., $100 \: A$) por vários segundos antes da fusão. Picos transientes de comutação com duração de microssegundos, portanto, não representam risco de atuação espúria. A função real do fusível é a proteção de último nível contra curtos-circuitos catastróficos (resistência praticamente nula no barramento), nos quais a corrente atingiria centenas de ampères independentemente da classificação do fusível. Nesse contexto, o modelo de $80 \: A$ oferece uma janela de proteção mais precisa para sobrecargas sustentadas acima da corrente nominal de $70 \: A$ do motor, enquanto permanece imune às correntes de pico transitórias. Adicionalmente, o modelo 0498080.M é um valor padronizado comercialmente com dimensões físicas e terminação definidas para a série MIDI, cujas especificações de capacidade de interrupção foram verificadas como adequadas ao barramento de $25{,}2 \: V$ do projeto.

A segunda divergência envolve a \textbf{topologia do banco de capacitores do barramento DC}. A metodologia projetou dois capacitores eletrolíticos de $470\,\mu\text{F}$ em paralelo, totalizando $940\,\mu\text{F}$. O projeto final emprega seis capacitores de $220\,\mu\text{F}$ em paralelo ($1320\,\mu\text{F}$) complementados por três capacitores cerâmicos de $1\,\mu\text{F}$. O argumento central para esta mudança é a redução da \textbf{ESR total do barramento}: associar seis unidades em paralelo divide a ESR equivalente por seis, enquanto duas unidades a dividem apenas por dois — resultando em uma corrente de ondulação (\textit{ripple}) por unidade três vezes menor, o que reduz drasticamente o aquecimento interno dos capacitores por efeito Joule ($P = I_{rms}^2 \cdot ESR$). Secundariamente, capacitores de $220\,\mu\text{F}$ são componentes de dimensões físicas reduzidas que permitem uma distribuição espacial mais uniforme ao redor dos drenos dos MOSFETs, encurtando o comprimento dos laços de comutação e, portanto, a indutância parasita do circuito. Os capacitores cerâmicos de $1\,\mu\text{F}$ complementam o banco no domínio de alta frequência, suprimindo transientes que os eletrolíticos não conseguem filtrar devido à sua \textbf{ESL} (Indutância Série Equivalente).

A terceira divergência refere-se à \textbf{topologia dos reguladores auxiliares}. Enquanto o texto preliminar previa reguladores em cascata (bateria $\rightarrow$ $15 \: V$ $\rightarrow$ $5 \: V$), o arranjo físico adota dois módulos LM2596 dispostos em paralelo, ambos alimentados diretamente pelo barramento DC. Esta decisão elimina o gargalo térmico de fazer o regulador de menor tensão processar toda a corrente do estágio primário, garantindo maior rendimento e isolamento galvânico entre o circuito de acionamento de \textit{gate} ($15 \: V$) e a lógica de processamento digital ($5 \: V$).

\subsection{Unidade de Processamento Lógico e Interface de Acionamento}

A Figura \ref{fig:esquematico_control} ilustra o núcleo de inteligência do ESC e sua interface direta com o estágio de potência. A Unidade de Processamento, baseada no módulo ESP32 (Figura \ref{fig:control_esp32}), é alimentada pela malha de $5 \: V$ (\textit{Vcc 2}). O regulador linear interno do microcontrolador reduz essa tensão para $3,3 \: V$, sinal que é exportado pelo pino 1 sob a nomenclatura \textit{Vmicro Ref}. Esta estratégia de projeto é fundamental: o \textit{Vmicro Ref} é roteado diretamente para os pinos de alimentação lógica (\textit{VDD}) dos três \textit{drivers} IR2110 (Figura \ref{fig:control_drivers}). Isso garante que o limiar de transição lógica (\textit{logic high threshold}) dos \textit{drivers} seja idêntico à tensão de saída dos pinos GPIO do ESP32, eliminando falhas de interpretação de sinal por incompatibilidade de níveis de tensão.

O isolamento contra ruídos é efetivado pela segregação dos planos de terra nos \textit{drivers} IR2110. O referencial lógico (\textit{VSS}) é conectado exclusivamente ao terra de sinal (\textbf{SGND}), enquanto o retorno de potência (\textit{COM}), que lida com os pulsos de alta corrente de carga e descarga dos MOSFETs, é roteado para o terra de potência (\textbf{PGND}). A comunicação de segurança entre o microcontrolador e os \textit{drivers} ocorre de forma redundante: o ESP32 gera os seis sinais do MCPWM ($AH, AL$, etc.) e possui controle direto sobre os pinos de \textit{Shutdown} ($SD$) de cada IR2110. Adicionalmente, o pino \textit{OC Trip} (\textit{Overcurrent Trip}) permite que um evento de falta detectado pelos sensores interrompa a geração de PWM no \textit{hardware} do ESP32 em microssegundos.

\begin{figure}[H]
    \centering
    \caption{Esquemáticos do núcleo de controle e interface de potência: (a) Microcontrolador ESP32-WROOM-32; (b) Estágio de translação de nível com \textit{drivers} IR2110.}
    \label{fig:esquematico_control}
    \begin{subfigure}[b]{0.48\textwidth}
        \centering
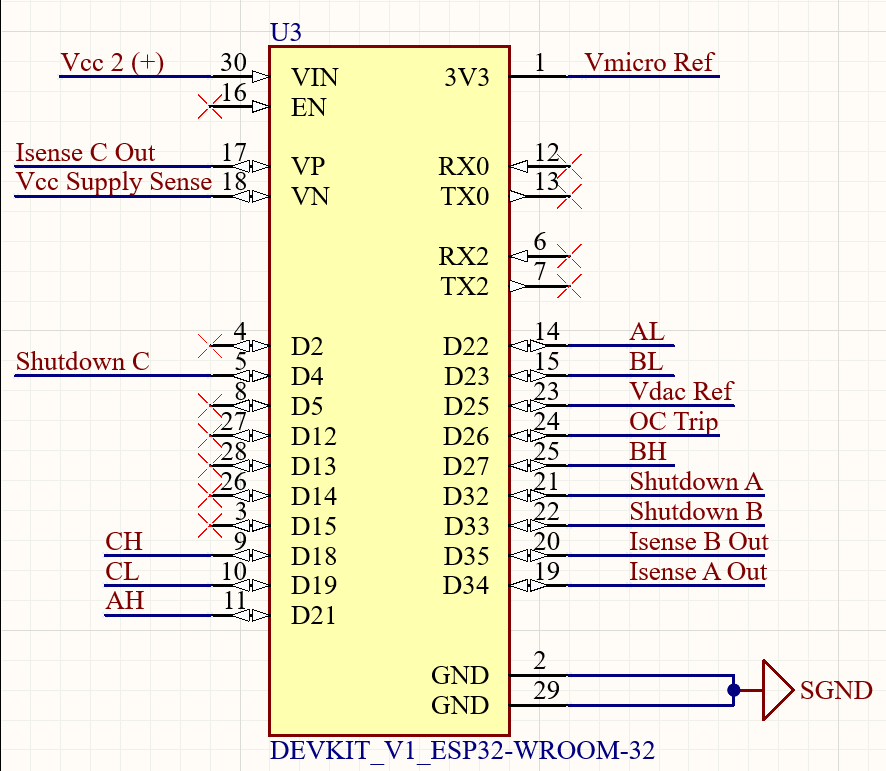
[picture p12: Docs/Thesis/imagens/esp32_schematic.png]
        
        \caption{Unidade de Processamento (ESP32).}
        \label{fig:control_esp32}
    \end{subfigure}
    \hfill
    \begin{subfigure}[b]{0.48\textwidth}
        \centering
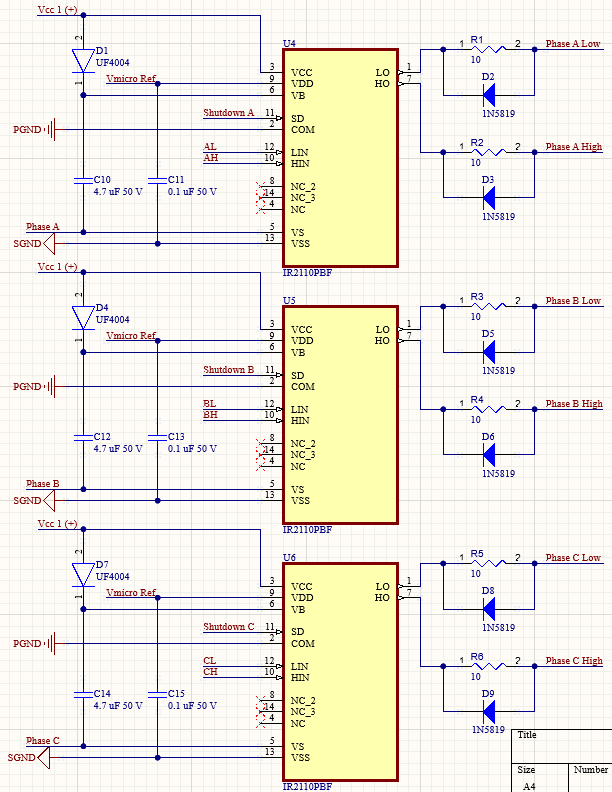
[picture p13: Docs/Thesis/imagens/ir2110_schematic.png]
        
        \caption{\textit{Drivers} de \textit{Gate} (IR2110).}
        \label{fig:control_drivers}
    \end{subfigure}
    \legendafonte{Elaborado pelo autor (2026).}
\end{figure}

\FloatBarrier
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

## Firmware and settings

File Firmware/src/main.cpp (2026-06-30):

/*
 * main.cpp — Ponto de entrada Arduino: setup(), loop() e orquestração do ESC.
 *
 * Camada: aplicação. Cadências no loop():
 *   - Contínuo: battery_monitor_tick, fsm_system_tick
 *   - 20 ms: polling PS4 e tradução para arm/disarm/setpoints
 *   - 500 ms: telemetria serial (somente leitura, 115200 baud)
 *
 * A malha de controle (1 kHz) executa em esp_timer dentro de motor_control — não no loop().
 */

#include <Arduino.h>
#include <esp_system.h>   /* esp_get_free_heap_size() — Sub-teste 5.2 */

#include "battery_monitor.h"
#include "board_config.h"
#include "esc_radio_quiet.h"
#include "fsm_system.h"
#include "hal_motor.h"
#include "ina240_current_sensors.h"
#include "motor_control.h"
#include "ps4_input.h"
#if BOARD_ENABLE_PS4_BT
#include "ps4_bt_host.h"
#endif
#if BOARD_ENABLE_SERIAL_HMI
#include "serial_hmi.h"
#endif
#include "wifi_telemetry.h"

static uint32_t s_last_telemetry_ms = 0;
static bool s_require_r2_release = false;

static bool is_run_phase_for_telemetry(motor_start_phase_t phase)
{
    return phase == MOTOR_START_RUN || phase == MOTOR_START_RUN_OPEN ||
           phase == MOTOR_START_RUN_SPEED;
}

/** Imprime diagnóstico na Serial: estado FSM, correntes, VBAT, RPM/duty em RUNNING. */
static void print_telemetry(const ps4_input_state_t *ps4)
{
#if BOARD_ENABLE_SERIAL_HMI
    Serial.printf("[%s] HMI=SER  R2=%u(rest=%u eff=%u)",
                  fsm_system_state_name(fsm_system_get_state()),
                  (ps4 != nullptr) ? static_cast<unsigned>(ps4->r2_raw) : 0U,
                  (ps4 != nullptr) ? static_cast<unsigned>(ps4->r2_rest) : 0U,
                  (ps4 != nullptr) ? static_cast<unsigned>(ps4->r2_effective) : 0U);
#elif BOARD_ENABLE_PS4_BT
    Serial.printf("[%s] BT=%s link=%s  R2=%u(rest=%u eff=%u)",
                  fsm_system_state_name(fsm_system_get_state()),
                  (ps4 != nullptr && ps4->connected) ? "ON" : "OFF",
                  ps4_bt_host_link_state_name(ps4_bt_host_get_link_state()),
                  (ps4 != nullptr) ? static_cast<unsigned>(ps4->r2_raw) : 0U,
                  (ps4 != nullptr) ? static_cast<unsigned>(ps4->r2_rest) : 0U,
                  (ps4 != nullptr) ? static_cast<unsigned>(ps4->r2_effective) : 0U);
#else
    Serial.printf("[%s] HMI=OFF  R2=%u(rest=%u eff=%u)",
                  fsm_system_state_name(fsm_system_get_state()),
                  (ps4 != nullptr) ? static_cast<unsigned>(ps4->r2_raw) : 0U,
                  (ps4 != nullptr) ? static_cast<unsigned>(ps4->r2_rest) : 0U,
                  (ps4 != nullptr) ? static_cast<unsigned>(ps4->r2_effective) : 0U);
#endif
    Serial.printf("  bolinha=%u",
                  (ps4 != nullptr && ps4->circle_pressed) ? 1U : 0U);

    Serial.printf("  I: A=%+.2f  B=%+.2f  C=%+.2f A  VBAT=%.1f V  pack=%uS  uvlo=%s",
                  ina240_read_amps(INA240_PHASE_A),
                  ina240_read_amps(INA240_PHASE_B),
                  ina240_read_amps(INA240_PHASE_C),
                  battery_monitor_get_volts_filtered(),
                  static_cast<unsigned>(battery_monitor_get_cell_count_s()),
                  battery_monitor_uvlo_active() ? "ATIVO" : "OK");

    if (fsm_system_get_state() == ESC_STATE_FAULT &&
        motor_control_get_last_fault_reason() != MOTOR_FAULT_NONE) {
        Serial.printf("  falha=%s",
                      motor_control_fault_reason_name(
                          motor_control_get_last_fault_reason()));
    }

    if (fsm_system_get_state() == ESC_STATE_RUNNING) {
        Serial.printf("  mode=%s  dir=%s  start=%s",
                      motor_control_control_mode_name(
                          motor_control_get_control_mode()),
                      motor_control_direction_name(motor_control_get_direction()),
                      motor_control_start_phase_name(motor_control_get_start_phase()));

#if MOTOR_CONTROL_DEFAULT_MODE == MOTOR_CONTROL_MODE_SPEED
        Serial.printf("  RPM=%.0f/%.0f(%.0f)",
                      motor_control_get_measured_rpm(),
                      motor_control_get_target_rpm(),
                      motor_control_get_target_command_rpm());
#endif

        Serial.printf("  I=%.2f/%.2f(%.2f)A  duty=%.1f%%  step=%u  comm=%s",
                      motor_control_get_measured_amps(),
                      motor_control_get_target_amps(),
                      motor_control_get_target_command_amps(),
                      motor_control_get_duty_percent(),
                      static_cast<unsigned>(motor_control_get_commutation_step()),
                      motor_control_comm_mode_name(motor_control_get_comm_mode()));

        if (is_run_phase_for_telemetry(motor_control_get_start_phase()) &&
            motor_control_get_comm_mode() == MOTOR_COMM_OPEN_LOOP) {
            Serial.printf("  f_el=%.1f Hz", motor_control_get_open_loop_comm_hz());
        }

        Serial.printf("  Kp=%.2f Ki=%.1f",
                      motor_control_get_pi_kp(),
                      motor_control_get_pi_ki());

        /* Sub-teste 5.1: latência do tick em µs (last / min / max desde o boot) */
        Serial.printf("  tick=%lu/%lu/%lu us",
                      (unsigned long)motor_control_get_tick_latency_us(),
                      (unsigned long)motor_control_get_tick_latency_min_us(),
                      (unsigned long)motor_control_get_tick_latency_max_us());

        if (!hal_motor_is_armed()) {
            Serial.print("  PWM=DESARM");
        }
    }

    /* Sub-teste 5.2: heap livre do FreeRTOS em bytes */
    Serial.printf("  heap=%lu B", (unsigned long)esp_get_free_heap_size());

    if (s_require_r2_release) {
        Serial.print("  aguardando_R2=0");
    }

    Serial.println();
}

static ps4_led_status_t led_status_from_fsm(bool connected, esc_state_t state)
{
    if (!connected) {
        return PS4_LED_OFF;
    }

    switch (state) {
    case ESC_STATE_INIT:
        return PS4_LED_INIT;
    case ESC_STATE_IDLE:
        return PS4_LED_IDLE;
    case ESC_STATE_RUNNING:
        return PS4_LED_RUNNING;
    case ESC_STATE_FAULT:
        return PS4_LED_FAULT;
    default:
        return PS4_LED_IDLE;
    }
}

/**
 * @brief Traduz estado do PS4 em requisições para FSM e motor_control.
 * Máquina de decisão do operador — ver etapas numeradas abaixo.
 */
static void apply_ps4_to_esc(const ps4_input_state_t *st)
{
    if (st == nullptr) {
        return;
    }

    // Etapa 1: perda de Bluetooth — desarme imediato se em RUNNING
    if (!st->connected) {
        if (fsm_system_get_state() == ESC_STATE_RUNNING) {
            fsm_system_request_disarm();
            s_require_r2_release = true;
        }
        return;
    }

    // Etapa 2: Options (borda) em FAULT — clear fault; exige soltar R2 antes de re-armar
    if (st->options_pressed && fsm_system_get_state() == ESC_STATE_FAULT) {
        if (fsm_system_clear_fault()) {
            s_require_r2_release = true;
        }
        return;
    }

    // Etapa 2b: Share (borda) — desarme imediato em RUNNING (fallback se R2 colado)
    if (st->share_pressed && fsm_system_get_state() == ESC_STATE_RUNNING) {
        fsm_system_request_disarm();
        s_require_r2_release = true;
        motor_control_set_target_amps(0.0f);
        motor_control_set_target_rpm(0.0f);
        return;
    }

    // Etapa 3: em FAULT sem clear — ignora demais entradas
    if (fsm_system_get_state() == ESC_STATE_FAULT) {
        return;
    }

    // Etapa 4: após clear fault ou desarme, aguarda gatilho solto antes de re-armar
    if (s_require_r2_release) {
        if (st->throttle_active) {
            return;
        }

        s_require_r2_release = false;
    }

    // Etapa 5: gatilho solto (pós-cal) — desarm e zera setpoint
    if (!st->throttle_active) {
        if (fsm_system_get_state() == ESC_STATE_RUNNING) {
            fsm_system_request_disarm();
            s_require_r2_release = true;
        }

        motor_control_set_target_amps(0.0f);
        motor_control_set_target_rpm(0.0f);
        motor_control_set_direction(st->direction);
        return;
    }

    // Etapa 6: aguarda calibração R2 e pressão do gatilho para arm em IDLE
    if (fsm_system_get_state() == ESC_STATE_IDLE) {
#if !BOARD_ENABLE_SERIAL_HMI
        if (!ps4_input_r2_calibrated()) {
            return;
        }
#endif

        if (!fsm_system_request_arm()) {
            return;
        }
    }

    // Etapa 7: só aplica setpoint se efetivamente em RUNNING
    if (fsm_system_get_state() != ESC_STATE_RUNNING) {
        return;
    }

    motor_control_set_direction(st->direction);

#if MOTOR_CONTROL_DEFAULT_MODE == MOTOR_CONTROL_MODE_SPEED
    motor_control_set_target_rpm(st->target_rpm);
#else
    motor_control_set_target_amps(st->target_amps);
#endif
}

/**
 * @brief Serializa o estado atual do ESC como JSON e envia via WebSocket.
 *
 * Campos do JSON (chaves curtas para minimizar bytes over-the-air):
 *   t=millis, ia/ib/ic=correntes fase, im=I medida, it=I alvo, itc=I cmd,
 *   d=duty%, v=VBAT, rpm=RPM medido, rpmt=RPM alvo, rpmtc=RPM cmd,
 *   fel=f elétrica Hz, kp/ki=ganhos PI, lat/lmin/lmax=latência tick µs,
 *   heap=heap livre bytes, state=FSM(0-3), phase=partida(0-4),
 *   step=passo 6-step, cmode=modo comutação(0=OPEN,1=ZCD),
 *   uvlo=bool, ps4c=PS4 conectado, r2=R2%, circle=bool, fault=string.
 */
static void push_wifi_telemetry_full(const ps4_input_state_t *ps4)
{
    if (wifi_telemetry_client_count() == 0) {
        return;
    }

    const esc_state_t state = fsm_system_get_state();
    const bool running = (state == ESC_STATE_RUNNING);
    const bool connected = (ps4 != nullptr && ps4->connected);

#if WIFI_TELEMETRY_DEFER_IN_RUNNING
    const bool batch_ready = wifi_telemetry_running_batch_ready();
#else
    const bool batch_ready = false;
#endif

    char json[420];
    snprintf(json, sizeof(json),
        "{"
        "\"t\":%lu,"
        "\"ia\":%.2f,\"ib\":%.2f,\"ic\":%.2f,"
        "\"im\":%.2f,\"it\":%.2f,\"itc\":%.2f,"
        "\"d\":%.1f,\"v\":%.2f,"
        "\"rpm\":%.0f,\"rpmt\":%.0f,\"rpmtc\":%.0f,"
        "\"fel\":%.1f,"
        "\"kp\":%.2f,\"ki\":%.1f,"
        "\"lat\":%lu,\"lmin\":%lu,\"lmax\":%lu,"
        "\"heap\":%lu,"
        "\"state\":%d,\"phase\":%d,\"step\":%d,\"cmode\":%d,"
        "\"uvlo\":%s,"
        "\"ps4c\":%s,\"r2\":%u,\"circle\":%s,"
        "\"fault\":\"%s\""
#if WIFI_TELEMETRY_DEFER_IN_RUNNING
        ",\"batch_ready\":%s"
#endif
        "}",
        (unsigned long)millis(),
        ina240_read_amps(INA240_PHASE_A),
        ina240_read_amps(INA240_PHASE_B),
        ina240_read_amps(INA240_PHASE_C),
        running ? motor_control_get_measured_amps()      : 0.0f,
        running ? motor_control_get_target_amps()        : 0.0f,
        running ? motor_control_get_target_command_amps(): 0.0f,
        running ? motor_control_get_duty_percent()       : 0.0f,
        battery_monitor_get_volts_filtered(),
        running ? motor_control_get_measured_rpm()       : 0.0f,
        running ? motor_control_get_target_rpm()         : 0.0f,
        running ? motor_control_get_target_command_rpm() : 0.0f,
        running ? motor_control_get_open_loop_comm_hz()  : 0.0f,
        motor_control_get_pi_kp(),
        motor_control_get_pi_ki(),
        (unsigned long)motor_control_get_tick_latency_us(),
        (unsigned long)motor_control_get_tick_latency_min_us(),
        (unsigned long)motor_control_get_tick_latency_max_us(),
        (unsigned long)esp_get_free_heap_size(),
        static_cast<int>(state),
        static_cast<int>(motor_control_get_start_phase()),
        static_cast<int>(motor_control_get_commutation_step()),
        static_cast<int>(motor_control_get_comm_mode()),
        battery_monitor_uvlo_active() ? "true" : "false",
        connected ? "true" : "false",
        connected ? static_cast<unsigned>(ps4->r2_raw * 100U / 255U) : 0U,
        (connected && ps4->circle_pressed) ? "true" : "false",
        (state == ESC_STATE_FAULT)
            ? motor_control_fault_reason_name(motor_control_get_last_fault_reason())
            : ""
#if WIFI_TELEMETRY_DEFER_IN_RUNNING
        , batch_ready ? "true" : "false"
#endif
    );

    wifi_telemetry_push(json);
}

#if BOARD_ENABLE_WIFI_TELEMETRY && !WIFI_TELEMETRY_DEFER_IN_RUNNING
static void push_wifi_telemetry(const ps4_input_state_t *ps4)
{
    push_wifi_telemetry_full(ps4);
}
#endif

/** Boot: Serial, PS4, init da FSM (HAL, drivers, timer 1 kHz). */
void setup()
{
    /* Segurança de potência antes de Wi-Fi/BT: SD em shutdown e pinos PWM em GPIO LOW. */
    (void)hal_motor_init();

    Serial.begin(115200);
    delay(100);

    esc_radio_quiet_init();

    Serial.println("\n--- ESC BLDC: bancada inversor ---");
#if BOARD_ENABLE_SERIAL_HMI
    Serial.println("HMI: Serial USB (monitor 115200).");
    Serial.println("  A/a = arm/disarm   + = sobe setpoint   - = desce setpoint   espaco = e-stop");
    Serial.println("  c/C = clear fault (sai de FAULT para IDLE)");
#elif BOARD_ENABLE_PS4_BT
    Serial.println("--- ESC BLDC: controle PS4 (Bluepad32) ---");
    Serial.println("Pairing PS4: Share + PS ate LED piscar; ESP32 escaneia automaticamente.");
    Serial.printf("R2: aguarde cal (2 s em repouso, R2=0) antes de pressionar.\n");
#endif
    Serial.println("Serial: telemetria somente leitura.");
#if BOARD_ENABLE_BEMF_ZCD
    Serial.println("ZCD BEMF: habilitado (handover OPEN->ZCD se hardware OK)");
#else
    Serial.println("ZCD BEMF: desabilitado — comutacao malha aberta com rampa");
#endif
#if MOTOR_SWAP_PHASES_BC
    Serial.println("Motor: MOTOR_SWAP_PHASES_BC=1 (fases B/C trocadas)");
#endif
#if MOTOR_BENCH_FIX_RUN_OPEN_F_EL
    Serial.printf("Bancada: RUN_OPEN f_el fixo %.1f Hz (~%.0f RPM) — R2 arma/desarma\n",
                  (double)MOTOR_BENCH_RUN_OPEN_F_EL_HZ,
                  (double)(MOTOR_BENCH_RUN_OPEN_F_EL_HZ * 60.0f /
                           (float)MOTOR_POLE_PAIRS));
#endif
    Serial.printf("Controle: mode=%s  setpoint=%s",
                  motor_control_control_mode_name(motor_control_get_control_mode()),
#if MOTOR_CONTROL_DEFAULT_MODE == MOTOR_CONTROL_MODE_SPEED
                  "RPM");
#else
                  "corrente");
#endif
#if BOARD_ENABLE_PS4_BT
    Serial.println(" | Bolinha=CCW | Share=desarm | Options=clear fault");
#else
    Serial.println("");
#endif

    /* Wi-Fi ANTES do Bluetooth: o ESP-IDF exige que o modo Wi-Fi seja configurado
     * antes de o stack BT (Bluepad32) alocar o coexistence scheduler de rádio. */
#if BOARD_ENABLE_WIFI_TELEMETRY
    if (!wifi_telemetry_init()) {
        Serial.println("[WiFi] Dashboard desabilitado.");
    }
#else
    Serial.println("[WiFi] Dashboard desligado (BOARD_ENABLE_WIFI_TELEMETRY=0).");
#endif

#if BOARD_ENABLE_PS4_BT
    if (!ps4_input_init()) {
        Serial.println("[PS4] init: FALHA");
    }
#else
    Serial.println("[PS4] Bluetooth desligado (BOARD_ENABLE_PS4_BT=0).");
#endif

#if BOARD_ENABLE_SERIAL_HMI
    if (!serial_hmi_init()) {
        Serial.println("[Serial HMI] init: FALHA");
    } else {
        Serial.println("[Serial HMI] ativo (Core 0, poll 20 ms).");
    }
#endif

    if (!fsm_system_init()) {
        Serial.println("fsm_system_init: FAULT");
    } else {
        if (!hal_motor_reclaim_outputs()) {
            Serial.println("[HAL] reclaim SD FALHOU");
        }
        Serial.printf("fsm_system_init: %s\n",
                      fsm_system_state_name(fsm_system_get_state()));
        Serial.printf("Pack LiPo: %uS (auto)  UVLO cutoff=%.1f V  recover=%.1f V\n",
                      static_cast<unsigned>(battery_monitor_get_cell_count_s()),
                      battery_monitor_get_uvlo_cutoff_v(),
                      battery_monitor_get_uvlo_recover_v());
#if MOTOR_CONTROL_DEFAULT_MODE == MOTOR_CONTROL_MODE_SPEED
        Serial.printf("Velocidade: max %.0f RPM  handover OPEN %.0f RPM\n",
                      MOTOR_SPEED_MAX_RPM,
                      MOTOR_SPEED_OPEN_LOOP_HANDOVER_RPM);
#endif
        Serial.printf("INA240 offset: A=%.0f  B=%.0f  C=%.0f mV\n",
                      ina240_get_offset_mv(INA240_PHASE_A),
                      ina240_get_offset_mv(INA240_PHASE_B),
                      ina240_get_offset_mv(INA240_PHASE_C));
    }
}

/**
 * @brief Loop principal Arduino (~20 ms efetivo para PS4; jitter tolerável).
 * Supervisão e entrada aqui; malha 1 kHz no esp_timer (motor_control_tick).
 */
void loop()
{
    battery_monitor_tick(millis());
    fsm_system_tick();

    static uint32_t last_poll_ms = 0;
    static ps4_input_state_t ps4 = {};

    const uint32_t now_ms = millis();
    const esc_state_t esc_state = fsm_system_get_state();

    static esc_state_t s_prev_esc_state = ESC_STATE_INIT;

    if (esc_state != s_prev_esc_state) {
        Serial.printf("[FSM] %s -> %s\n",
                      fsm_system_state_name(s_prev_esc_state),
                      fsm_system_state_name(esc_state));
    }

#if BOARD_ENABLE_WIFI_TELEMETRY && WIFI_TELEMETRY_DEFER_IN_RUNNING
    static uint32_t s_last_light_wifi_ms = 0;

    if (esc_state == ESC_STATE_RUNNING && s_prev_esc_state != ESC_STATE_RUNNING) {
        wifi_telemetry_clear_running_batch();
    }
    if (s_prev_esc_state == ESC_STATE_RUNNING &&
        (esc_state == ESC_STATE_IDLE || esc_state == ESC_STATE_FAULT)) {
        wifi_telemetry_finalize_running_batch();
        if (wifi_telemetry_client_count() > 0) {
            push_wifi_telemetry_full(&ps4);
        }
    }
#endif

    s_prev_esc_state = esc_state;

    if ((now_ms - last_poll_ms) >= PS4_INPUT_POLL_MS) {
        last_poll_ms = now_ms;

#if BOARD_ENABLE_PS4_BT
        if (ps4_input_update(&ps4)) {
            apply_ps4_to_esc(&ps4);

            ps4_input_set_led_status(
                led_status_from_fsm(ps4.connected, fsm_system_get_state()));
        }
#elif BOARD_ENABLE_SERIAL_HMI
        if (serial_hmi_update(&ps4)) {
            const esc_state_t fsm_before = fsm_system_get_state();
            apply_ps4_to_esc(&ps4);
            const esc_state_t fsm_after = fsm_system_get_state();

            if (fsm_before != fsm_after) {
                Serial.printf("[FSM] %s -> %s\n",
                              fsm_system_state_name(fsm_before),
                              fsm_system_state_name(fsm_after));
                s_prev_esc_state = fsm_after;
            }
        }
#endif
    }

    /* Telemetria serial 500 ms (IDLE e RUNNING). Wi-Fi push só com dashboard ativo. */
#if BOARD_ENABLE_WIFI_TELEMETRY
    const uint32_t telem_interval_ms =
        (esc_state == ESC_STATE_RUNNING ||
         wifi_telemetry_client_count() > 0) ? 100U : 500U;
#else
    const uint32_t telem_interval_ms = 500U;
#endif

    if ((now_ms - s_last_telemetry_ms) >= telem_interval_ms) {
        s_last_telemetry_ms = now_ms;
        print_telemetry(&ps4);
#if BOARD_ENABLE_WIFI_TELEMETRY
#if WIFI_TELEMETRY_DEFER_IN_RUNNING
        if (esc_state == ESC_STATE_RUNNING) {
            wifi_telemetry_record_running_sample(
                now_ms,
                motor_control_get_measured_rpm(),
                motor_control_get_measured_amps(),
                motor_control_get_duty_percent(),
                motor_control_get_open_loop_comm_hz());
            if (wifi_telemetry_client_count() > 0 &&
                (now_ms - s_last_light_wifi_ms) >= 1000U) {
                s_last_light_wifi_ms = now_ms;
                const bool ps4_conn = ps4.connected;
                wifi_telemetry_push_light_running_status(
                    now_ms,
                    wifi_telemetry_running_buf_count(),
                    ps4_conn,
                    ps4_conn ? static_cast<uint8_t>(ps4.r2_raw * 100U / 255U) : 0U);
            }
        } else {
            push_wifi_telemetry_full(&ps4);
        }
#else
        push_wifi_telemetry(&ps4);
#endif
#endif
    }

#if BOARD_ENABLE_WIFI_TELEMETRY && WIFI_TELEMETRY_DEFER_IN_RUNNING
    s_prev_esc_state = esc_state;
#endif

    vTaskDelay(1);
}

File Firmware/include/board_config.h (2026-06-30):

/*
 * board_config.h — Configuração central do hardware e parâmetros do ESC.
 *
 * Camada: configuração em tempo de compilação (incluída por HAL, drivers e controle).
 * Única fonte de verdade para pinos GPIO, limites operacionais e ganhos PI.
 * Alterar um pino ou limiar aqui propaga-se a todo o firmware sem mudar lógica de módulos.
 *
 * Ref.: Hardware/PCB_Project/ESP32_PINMAP.md, esp32_devkitC_v4_pinlayout.png
 */

#ifndef BOARD_CONFIG_H
#define BOARD_CONFIG_H

/* Pinos reservados pelo silício — não usar para o ESC */
// JTAG (ESP-Prog): GPIO12 MTDI, 13 MTCK, 14 TMS, 15 MTDO
// Flash SPI interna: GPIO6–11

// ==========================================
// MAPEAMENTO LÓGICO DEFINITIVO (PORTAS 'D')
// ==========================================

// --- FASE A ---
#define PIN_AH            19
#define PIN_AL            22
#define PIN_SHUTDOWN_A    32

// --- FASE B ---
#define PIN_BH            27
#define PIN_BL            23
#define PIN_SHUTDOWN_B    33

// --- FASE C ---
#define PIN_CH            15
#define PIN_CL            18
#define PIN_SHUTDOWN_C    4

/* Aliases legados (hal_pwm / docs) */
#define PIN_PWM_AH        PIN_AH
#define PIN_PWM_AL        PIN_AL
#define PIN_PWM_BH        PIN_BH
#define PIN_PWM_BL        PIN_BL
#define PIN_PWM_CH        PIN_CH
#define PIN_PWM_CL        PIN_CL
#define PIN_SD_A          PIN_SHUTDOWN_A
#define PIN_SD_B          PIN_SHUTDOWN_B
#define PIN_SD_C          PIN_SHUTDOWN_C

/** IR2110 SD (datasheet): HIGH = HO/LO High-Z; LOW = segue HIN/LIN. */
#define IR2110_SD_SHUTDOWN_LEVEL  1
#define IR2110_SD_ENABLE_LEVEL    0

// --- SENSORES DE CORRENTE E TENSÃO ---
#define PIN_ISENSE_A      34
#define PIN_ISENSE_B      35
#define PIN_ISENSE_C      36  /* VP */
#define PIN_VCC_SENSE     39  /* VN */
#define PIN_ADC_IA        PIN_ISENSE_A
#define PIN_ADC_IB        PIN_ISENSE_B
#define PIN_ADC_IC        PIN_ISENSE_C
#define PIN_ADC_VBAT      PIN_VCC_SENSE

/** Calibração de offset INA240 no boot (128 amostras por fase). */
#define INA240_CALIBRATION_SAMPLES  128U
/** Filtro EMA em runtime (1 ADC/leitura): A mais lento (GPIO 34 ruidoso); B/C inalterados. */
#define INA240_MV_EMA_ALPHA_A       0.05f
#define INA240_MV_EMA_ALPHA_BC      0.25f
#define INA240_NOMINAL_OFFSET_MV    1650.0f

/** Vref interno do ADC ESP32 (mV) para esp_adc_cal quando eFuse ausente — NÃO é 3300 mV. */
#define ADC_DEFAULT_VREF_MV         1100U

/** Override de offset INA240 medido na bancada (Setup 1); 0 = offset = média ADC. */
#define INA240_USE_MANUAL_OFFSET    1
#define INA240_MANUAL_OFFSET_A_MV   1670.0f
#define INA240_MANUAL_OFFSET_B_MV   1480.0f
#define INA240_MANUAL_OFFSET_C_MV   1510.0f

/** Mediana de N leituras ADC só fase A (GPIO 34); 0 = desligado. */
#define INA240_A_MEDIAN_SAMPLES         16U

/** 2ª calibração INA240 após softAP (atualiza adc_zero/bench_corr com RF ativo). */
#define INA240_RECAL_AFTER_WIFI         1
#define INA240_RECAL_AFTER_WIFI_DELAY_MS 300U

/** 3ª calibração INA240 após ps4_input_init (regime BT scan ativo). */
#define INA240_RECAL_AFTER_PS4          0
#define INA240_RECAL_AFTER_PS4_DELAY_MS 500U

// --- PROTEÇÃO OCP (LM339) ---
#define PIN_VDAC_REF      25
#define PIN_OC_TRIP       26

/* --- ZCD BEMF (opcional): comparadores para comutação sensorless por cruzamento por zero --- */
// 0 = malha aberta (padrão). 1 = permite handover OPEN → ZCD fechado.
#define BOARD_ENABLE_BEMF_ZCD  0
#define PIN_ZCD_A     16   // U3 RX2 (pino símb. 6)
#define PIN_ZCD_B     17   // U3 TX2 (pino símb. 7)
#define PIN_ZCD_C     5    // U3 D5  (pino símb. 8); pull-up 10k no comparador

/** Atraso elétrico após ZCD até comutar (graus). Spec/tese: 30°. */
#define BEMF_COMM_DELAY_DEG_ELEC  30.0f

/** Eventos ZCD válidos consecutivos para handover malha aberta → fechada. */
#define BEMF_ZCD_HANDOVER_COUNT   6U

/* --- PWM e malha: frequência de comutação, dead-time e teto de duty (bootstrap IR2110) --- */
#define MAX_DUTY_CYCLE_PERCENT 95.0f
#define PWM_FREQUENCY_HZ       20000
#define DEAD_TIME_NS           500

#define CONTROL_LOOP_HZ        10000.0f
#define CONTROL_DT_S           (1.0f / CONTROL_LOOP_HZ)

/** Malha aberta: frequência elétrica inicial / máxima (Hz) e incremento por passo.
 *  Motor A2212/10T 1400kV (14 polos, p=7): teto de 300 Hz → ≈ 2571 RPM mecânicos.
 *  Limite garante FCEM detectável para handover ZCD sem perda de sincronismo (stall). */
#define MOTOR_OPEN_LOOP_COMM_HZ_START        5.0f
#define MOTOR_OPEN_LOOP_COMM_HZ_MAX          300.0f
#define MOTOR_OPEN_LOOP_COMM_HZ_RAMP_PER_STEP 1.5f
#define MOTOR_OPEN_LOOP_COMM_HZ_MAX_LIMIT      300.0f
#define MOTOR_OPEN_LOOP_COMM_RAMP_MIN          0.1f
#define MOTOR_OPEN_LOOP_COMM_RAMP_MAX          20.0f
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

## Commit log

2025-08-19 Atualiza descrição da equação de tensão aplicada, detalhando os termos relacionados à Armadura em motores elétricos.
2025-08-19 Corrige erro de digitação na descrição da tensão aplicada em motores elétricos.
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2026-01-09 Adição de nova referência técnica sobre seleção de componentes bootstrap para ICs de controle
2026-01-09 Adição de seções sobre indutância parasita e filtragem do barramento DC, incluindo dimensionamento de capacitores e análise de sensoriamento de corrente.
2026-01-10 Adição de cálculos e considerações sobre capacitância mínima e dimensionamento de capacitores para filtragem do barramento DC.
2026-01-12 Adição de seções sobre frequência de chaveamento, análise de perdas, mitigação de ruído acústico e validação do driver, incluindo referências bibliográficas.
2026-01-12 Atualização da seção sobre ripple de corrente e torque, incluindo estimativas de indutância e resistência para motores BLDC, e análise da constante de tempo elétrica.
2026-01-12 Adição da seção sobre sistema de proteção contra sobrecorrentes, detalhando o uso de fusível MIDI e suas vantagens na segurança do sistema.
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2026-01-28 Adição do arquivo Draft1.asc com definição de componentes e atributos do circuito.
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2026-02-09 Atualização do arquivo .gitignore e adição de novos arquivos de simulação monofásica e trifásica
2026-02-10 Refatoração do circuito no arquivo monofasico.asc para simplificação e melhoria na legibilidade
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2026-03-31 Atualização da configuração do projeto PCB e adição de novos documentos de design
    [Control.SchDoc, PCB_Project.PrjPcb, Sensors.SchDoc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]
2026-03-31 Refactor code structure for improved readability and maintainability
    [Sheet1.SchDoc, Supply.SchDoc]
2026-03-31 Update PCB schematic files for Power, Sensors, and Supply modules
    [Control.SchDoc, Power.SchDoc, Sensors.SchDoc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]
2026-04-01 Update PCB project configuration and add new PCB document
    - Enabled project conflict prevention warnings in PCB project settings.
    - Adjusted annotation order settings for multiple documents to ensure proper sequencing.
    - Added a new document configuration for PCB.PcbDoc with annotation settings.
    - Updated specific lines in the configuration to correct annotation orders.
    - Binary differences detected in Power.SchDoc, Sensors.SchDoc, and Supply.SchDoc files.
    - Introduced a new PCB document (PCB.PcbDoc) with a size of 4250 KB.
    [Control.SchDoc, PCB_Project.PrjPcb, Power.SchDoc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]
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2026-04-08 Update PCB schematic files for Power and Sensors modules
    [Power.SchDoc, Sensors.SchDoc]
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2026-04-10 Versão 2: Star Ground e saída de corrente para os motores.
    [PCB1.PcbLib]
2026-04-10 Add initial output job configuration for PCB project
    - Created a new output job file for the PCB project.
    - Configured output settings for PDF, print jobs, and generated files.
    - Defined multiple output configurations for various layers and reports.
    - Set paths for output documents and preferences for BOM and multimedia outputs.
2026-04-10 Add initial PCB project file in Excel format
    - Created a new Excel file for the PCB project, containing relevant design and component information.
    [PCB_Project.xlsx]
2026-04-10 Atualização do arquivo .gitignore para ignorar o arquivo temporário do projeto PCB e substituição dos arquivos PCB_Project.xlsx e Supply.SchDoc.
    [PCB_Project.xlsx, Supply.SchDoc]
2026-04-16 Atualização do arquivo PCB_Project.xlsx com novas alterações de projeto.
    [PCB_Project.xlsx]
2026-04-22 Remoção do arquivo PCB_Project.xlsx do repositório.
    [PCB_Project.xlsx]
2026-04-24 Atualização para corrosão
    [PCB1.PcbLib, PCB_Project.PrjPcb]
2026-04-25 Ajuste do Conector XT90
    [PCB1.PcbLib, PCB_Project.SCHLIB]
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2026-04-29 Furos e Trilhas para CNC
    [PCB_Project.PrjPcb]
2026-04-29 Adição dos arquivos para CNC
    [PCB.GBL, PCB.GTL]
2026-04-29 Ajuste nas regras do .gitignore para incluir pastas de logs e exceções para arquivos de fabricação
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2026-04-29 Limpeza de arquivos 2
    [PCB1.PcbLib, PCB_Project.PrjPcb, PCB_Project.SCHLIB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]
2026-04-29 Revisão do Gitignore e adição de arquivos de saída
    [PCB.GBL, PCB.GTL]
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2026-05-15 Alteração de Arquivos CNC para melhor compatibilidade
    [PCB.GBL, PCB.GTL]
2026-05-18 Mudança do nome da pasta, melhorias, e geração de imagens da simulação.
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2026-05-21 Add README for Electronic Speed Controller project
    This README outlines the project overview, tech stack, repository structure, engineering stages, development roadmap, and contact information for the Electronic Speed Controller (ESC) project.
2026-05-21 - Atualização dos resistores no esquemático do Altium e simulação - Lista de próximos passos - Dados novos exportados
    [Control.SchDoc, Power.SchDoc, Sensors.SchDoc]
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2026-05-22 Adição do texto de sensores.
    [Sensors.SchDoc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]
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2026-06-09 Update PCB outputs and add DAC HAL implementation
    - Updated NC Drill report with new date and hole counts.
    - Modified Layer Pairs Export File path for PCB project.
    - Added new coordinates to PCB.TXT for drill holes.
    - Updated Status Report with new output generation timestamp.
    - Implemented DAC HAL with functions for initialization, setting, and getting voltage.
    - Created header file for DAC HAL.
    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
    [Control.SchDoc, PCB.PcbDoc, PCB_Project.PrjPcb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]
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2026-06-15 feat: Update motor control documentation and safety analysis
    - Added detailed documentation on the behavior of direction change with the Circle button while the motor is in operation, including the conditions that block this action.
    - Documented the procedure for safely reversing motor direction and the risks associated with automatic direction reversal while the motor is moving.
    - Included a safety analysis outlining necessary safeguards for implementing automatic direction reversal to prevent overcurrent faults.
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2026-06-24 feat: Enhance documentation and validation protocols for dashboard and motor control
    - Updated `MEMORIA_TCC.md` with detailed comparisons of RPM metrics and added new validation sections for the dashboard's performance against physical references.
    - Expanded `DOCUMENTACAO_PROGRAMACAO.md` to include a comprehensive protocol for validating the dashboard's telemetry capabilities and its impact on system latency.
    - Revised `4_resultados_discussao.tex` to reflect new findings on the dashboard's performance and stability during extended operation without USB connections.
    - Improved clarity in `1_introducao_teorica.tex` and `3_metodologia.tex` regarding the implementation of sensorless control and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
2026-06-29 feat: Refine motor control and calibration processes in firmware and documentation
    - Enhanced `4_resultados_discussao.tex` with detailed explanations of the control architecture and the role of the HAL in managing ADC readings and PWM signals.
    - Updated `DOCUMENTACAO_PROGRAMACAO.md` to clarify the initialization sequence for the INA240 current sensors and the impact of RF noise on ADC readings.
    - Improved the calibration process for the INA240, detailing the three-step boot calibration and runtime recalibration methods.
    - Revised flowcharts in the documentation to reflect changes in the initialization and control flow, ensuring accurate representation of the system's operation.
    - Added new f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
    [board_config.h, esc_boot_sensors.c, fsm_system.c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]
2026-06-29 refactor: Remove outdated thesis documentation files
    - Deleted `checklist_gamificado.md`, `main.bcf`, `main.lof`, `main.lot`, `main.pdf`, `main.run.xml`, and `main.toc` as they are no longer relevant to the current project structure and documentation needs.
    - This cleanup helps streamline the repository and focuses on maintaining only essential files for the thesis.
    [board_config.h, main.cpp, wifi_telemetry.cpp]
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2026-06-30 feat: Update thesis documentation and bibliography for consistency and accuracy
    - Revised `bibliografia.bib` to update access dates for multiple references to June 26, 2026, ensuring consistency across citations.
    - Enhanced `main.tex` to reflect the correct year as 2026 and introduced a new command for source legends to improve formatting.
    - Updated chapter files to replace outdated caption commands with the new legend command for better citation clarity.
    - Added a new conclusion chapter in `3_metodologia.tex` to finalize the thesis structure and improve the overall flow of the document.
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2026-10-16 docs: document ESC architecture and validation limits
    Replace outdated planned-firmware claims with verified source, thesis evidence, build procedure and attribution. Documentation only; no build or physical test performed.
2026-10-17 docs: fix architecture table alignment
    Correct the three-column Markdown separator in the ESC README.
